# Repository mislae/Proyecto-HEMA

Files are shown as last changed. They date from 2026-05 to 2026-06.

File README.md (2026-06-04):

# Proyecto HEMA: Robot humanoide de 1 m

## Estado del proyecto
Proyecto HEMA esta actualmente en fase de diseno mecanico, bocetaje y validacion CAD 3D. El foco real del repositorio es el conjunto pie-tobillo y la estructura fisica necesaria para probar el primer prototipo.

En esta etapa no hay desarrollo de software activo en el alcance principal. Esos temas quedan como roadmap futuro, pero no deben confundirse con el entregable actual.

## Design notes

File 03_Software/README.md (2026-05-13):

# Software & Control Roadmap - Proyecto HEMA

Este módulo gestiona la inteligencia y el movimiento del robot, utilizando una arquitectura híbrida entre procesamiento de alto nivel (RPi 4B) y control de tiempo real (RPi Pico).

## 🧠 Control Architecture

*   **High-Level Logic (Raspberry Pi 4B):** Encargada de la visión computacional, cinemática inversa y la interfaz de teleoperación con **Meta Quest 3S**.
*   **Low-Level Actuation (Raspberry Pi Pico):** Encargada de la generación de señales PWM para los servos MG995 y la lectura de sensores locales.

---

## 🚀 Development Phases

### Phase 1: Basic Motion & PWM (Current)
*   **Target:** Raspberry Pi Pico.
*   **Tasks:**
    *   Implementación de drivers básicos en **MicroPython** para el control de posición de servos.
    *   Calibración del rango de movimiento del tobillo ($\pm 25^\circ$).
    *   Pruebas de torque estático bajo carga del frame de 1 metro.

### Phase 2: Smooth Motion & Kinematics
*   **Target:** RPi Pico + RPi 4B.
*   **Tasks:**
    *   Implementación de curvas de aceleración (Ease-in/out) para reducir el estrés mecánico en las piezas de **PETG**.
    *   Desarrollo de una API de comunicación serial (UART) entre ambos controladores.
    *   Cálculo de la cinemática del sistema de varillas (mapeo de grados del servo vs. grados reales del tobillo).

### Phase 3: Teleoperation & VR Integration
*   **Target:** RPi 4B + Meta Quest 3S.
*   **Tasks:**
    *   Transmisión de datos de teleoperación mediante **UDP/WebSockets**.
    *   Sincronización del pitch del tobillo con los sensores de movimiento del visor VR.
    *   Monitoreo de telemetría en tiempo real (consumo de corriente y ángulos).

---

## 🛠️ Tech Stack
*   **Languages:** Python 3.x, MicroPython.
*   **Communication:** UART, I2C, WebSockets.
*   **Libraries:** `machine` (Pico), `pyserial`, `numpy` (for kinematics).

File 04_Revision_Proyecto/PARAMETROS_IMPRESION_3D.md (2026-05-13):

# Parametros de impresion 3D - Proyecto HEMA

## Proposito
Este documento define el minimo tecnico que debe registrarse para imprimir piezas estructurales del Proyecto HEMA.

## Regla base
Cada pieza importante debe imprimirse con parametros conocidos y repetibles. No basta con decir "PETG" o "ABS"; hay que poder reproducir la pieza con el mismo comportamiento mecanico.

## Campos que deben documentarse por pieza
- Material
- Altura de capa
- Numero de perímetros
- Relleno
- Porcentaje de relleno
- Tipo de soportes
- Orientacion de impresion
- Temperatura de boquilla
- Temperatura de cama
- Zona critica de carga
- Observaciones de postproceso

## Recomendacion de documentacion minima
Para cada pieza estructural, registrar al menos:
- nombre de la pieza
- version
- material usado
- orientacion de impresion
- razon de esa orientacion
- si requiere soportes o no
- ajuste esperado con piezas comerciales

## Piezas que requieren mas cuidado
- Alojamiento del tubo PVC
- Soporte del tobillo
- Brazos de linkage
- Soportes del servo
- Cualquier pieza que reciba carga concentrada o vibracion repetida

## Buenas practicas
- Orientar las capas para que no trabajen en la direccion mas debil de la pieza.
- Evitar soportes innecesarios en superficies funcionales.
- Preferir geometria simple si reduce riesgo de delaminacion.
- Hacer una prueba corta si se cambia material o relleno.

## Criterio de decision
Si una pieza es estructural y soporta carga, su configuracion de impresion debe quedar escrita antes de fabricar el lote final.

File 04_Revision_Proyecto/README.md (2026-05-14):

# Documentacion tecnica - Proyecto HEMA

Esta carpeta contiene documentacion de trabajo para la fase mecanica del proyecto.

## Uso diario
- `CHECKLIST_OPERATIVA.md`: control rapido antes de exportar, fabricar o cerrar una revision.
- `GUIA_ENSAMBLAJE.md`: secuencia de montaje y criterios de aceptacion del conjunto pie-tobillo.
- `PARAMETROS_IMPRESION_3D.md`: registro minimo para piezas impresas estructurales.

## Uso de coordinacion
- `GUIA_MECANICA_Y_FLUJO.md`: reglas de colaboracion, versionado CAD y publicacion.

## Uso historico
- `REVISION_TECNICA_HEMA.md`: diagnostico inicial que explica por que se ordeno esta carpeta.

## Orden recomendado para trabajar
1. Planificar cambio con `GUIA_MECANICA_Y_FLUJO.md`.
2. Validar salida con `CHECKLIST_OPERATIVA.md`.
3. Si hay pieza impresa, registrar en `PARAMETROS_IMPRESION_3D.md`.
4. Si afecta montaje, revisar `GUIA_ENSAMBLAJE.md`.

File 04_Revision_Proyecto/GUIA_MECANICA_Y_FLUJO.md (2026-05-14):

# Guia mecanica y flujo de trabajo - Proyecto HEMA

## Proposito
Esta guia define como trabajar el proyecto HEMA en su fase actual: diseno CAD, validacion mecanica y prototipado fisico del tobillo humanoide.

El objetivo es que dos personas puedan colaborar sin pisarse cambios, sin sobreescribir piezas y con una trazabilidad tecnica clara.

## Regla base de alcance
* Lo que vive en Fusion 360 es el modelo maestro.
* Lo que se sube al repositorio es la version controlada en STEP, PDF y notas tecnicas.
* El repositorio no debe convertirse en un archivo caotico de exportaciones no verificadas.

## Flujo de trabajo recomendado
### 1. Definir la tarea
Antes de abrir Fusion 360, la pieza o modificacion debe tener claro:
* problema mecanico a resolver
* pieza afectada
* riesgo tecnico
* criterio de exito

### Checklist operativa
Usa la lista de [CHECKLIST_OPERATIVA.md](CHECKLIST_OPERATIVA.md) antes de exportar cualquier nueva revision.
La idea es que la revision no dependa de memoria ni de revisiones informales.

### 2. Trabajar en una rama dedicada
Cada cambio mecanico debe desarrollarse en su propia rama.
* Una rama por pieza o por mejora concreta.
* No mezclar cambios de distintas zonas del robot en una sola entrega.

### 3. Exportar con version controlada
Nunca sobrescribir un STEP antiguo sin dejar rastro.
* Usar versionado explicito en el nombre del archivo.
* Mantener una secuencia clara: v1, v2, v3.
* Si una version queda descartada, no eliminarla sin documentarlo.

### 4. Registrar el cambio
Cada exportacion debe dejar nota en `01_Mechanical/DESIGN_LOG.md` con:
* que se modifico
* por que se modifico
* que problema tecnico corrige
* que queda pendiente de validar

### 5. Revisar antes de cerrar
Antes de aprobar una revision:
* comprobar interferencias
* revisar tolerancias
* verificar accesibilidad de tornillos y herramientas
* confirmar que el recorrido mecanico no bloquea

## Nomenclatura sugerida
Usar una convención simple y repetible:
* `HEMA_Pieza_v1.step`
* `HEMA_Pieza_v2.step`
* `HEMA_Conjunto_Tobillo_v3.step`

Para planos:
* `HEMA_Pieza_v1.pdf`
* `HEMA_Conjunto_Tobillo_v3.pdf`

## Reglas para evitar conflictos entre dos personas
* No editar el mismo subconjunto de Fusion 360 al mismo tiempo sin coordinacion previa.
* Si una persona modifica geometria estructural, la otra debe revisar tolerancias, ensamble o fabricacion, no tocar la misma pieza a la vez.
* Si hay dudas sobre la version correcta, se consulta el `DESIGN_LOG` antes de exportar otra revision.
* Nadie reemplaza archivos en silencio.

## Checklist tecnico antes de publicar una pieza
Esta validacion se ejecuta en `CHECKLIST_OPERATIVA.md`.
No dupliques esa lista aqui para evitar versiones inconsistentes.

## Parametros de impresion 3D que deben documentarse
Se documentan en `PARAMETROS_IMPRESION_3D.md`.
Este archivo solo define el flujo y la responsabilidad de hacerlo.

## Que debe existir en un hardware open-source serio
Este proyecto deberia terminar con al menos:
* guia de ensamblaje
* BOM mecanico completo
* parametros de impresion 3D
* tolerancias criticas
* vistas explotadas o subconjuntos
* protocolo de validacion del prototipo

## Orden de ataque recomendado
### Bloque 1: cierre mecanico
* resolver ajuste tubo PVC / alojamiento impreso
* definir abrazadera o sistema de retencion
* cerrar la tornilleria del tobillo

### Bloque 2: fabricacion
* fijar parametros de impresion
* verificar orientacion de carga
* preparar piezas para primer prototipo

### Bloque 3: validacion
* ensayo de carga estatica
* revision de juego mecanico
* control del desgaste inicial

## Criterio de calidad
La revision va bien si una persona externa puede responder sin adivinar:
* que pieza necesita
* como la imprime
* con que la ensambla
* que tolerancias son criticas
* como sabe si funciona o no

## Nota final
Mantener el proyecto simple no significa hacerlo superficial. Significa documentar solo lo necesario, pero hacerlo con rigor suficiente para que el conjunto sea reproducible y defendible tecnicamente.

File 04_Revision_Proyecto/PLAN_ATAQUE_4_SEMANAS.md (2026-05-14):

# Plan de ataque de 4 semanas - Proyecto HEMA

## Objetivo
Convertir el conjunto pie-tobillo en un prototipo mecanico reproducible, con tolerancias, ensamble y validacion minima cerrados.

## Tablero Kanban (seguimiento rapido)

| ID | Tarea | Responsable | Estado |
| :-- | :-- | :-- | :-- |
| W1-01 | Resolver holgura PVC-alojamiento | Martin / Companero | Todo |
| W1-02 | Definir retencion final (abrazadera/interferencia/hibrido) | Martin / Companero | Todo |
| W1-03 | Verificar recorrido completo sin interferencias | Martin / Companero | Todo |
| W2-01 | Cerrar tornilleria real en BOM | Martin / Companero | Todo |
| W2-02 | Definir parametros de impresion por pieza | Martin / Companero | Todo |
| W2-03 | Imprimir primera tanda de piezas | Martin / Companero | Todo |
| W3-01 | Ensamblar subconjunto pie-tobillo | Martin / Companero | Todo |
| W3-02 | Registrar incidencias de montaje | Martin / Companero | Todo |
| W3-03 | Corregir geometria por ajustes forzados | Martin / Companero | Todo |
| W4-01 | Ejecutar ensayo estatico de carga | Martin / Companero | Todo |
| W4-02 | Validar repetibilidad de movimiento | Martin / Companero | Todo |
| W4-03 | Revisar holguras y desgaste inicial | Martin / Companero | Todo |

Estados sugeridos: `Todo`, `Doing`, `Done`, `Blocked`.

## Reglas de uso del tablero
- Actualizar estado al cierre de cada jornada, no solo al final de la semana.
- Si una tarea queda en `Blocked`, anotar causa y siguiente accion en `01_Mechanical/DESIGN_LOG.md`.
- Si una tarea pasa a `Done`, verificar que tenga evidencia (STEP, BOM, nota tecnica o registro de prueba).
- No abrir tareas nuevas sin cerrar o desbloquear las criticas de la semana actual.

## Semana 1: Cierre de geometria critica
- Resolver holgura PVC-alojamiento.
- Definir estrategia de retencion final (abrazadera, interferencia o hibrido).
- Verificar recorrido completo del tobillo sin interferencias.
- Salida esperada: nuevo STEP de conjunto y nota tecnica en DESIGN_LOG.

## Semana 2: Tornilleria y fabricacion
- Cerrar lista de tornilleria real en BOM.
- Definir parametros de impresion para piezas estructurales.
- Imprimir primera tanda de piezas del tobillo.
- Salida esperada: BOM actualizado y registro de impresion por pieza.

## Semana 3: Ensamble y correcciones
- Ensamblar subconjunto completo pie-tobillo.
- Levantar incidencias de montaje y accesibilidad de herramientas.
- Corregir geometria si aparecen ajustes forzados.
- Salida esperada: guia de ensamblaje con observaciones reales del prototipo.

## Semana 4: Validacion mecanica minima
- Ensayo estatico de carga.
- Repetibilidad de movimiento en el rango objetivo.
- Revision de holguras y desgaste inicial.
- Salida esperada: estado de validacion documentado y decision de siguiente iteracion.

## Criterio de exito
Al final de la semana 4, una persona externa debe poder:
- entender que piezas fabricar,
- ensamblarlas sin improvisar,
- y evaluar si el conjunto cumple o no con criterios basicos.

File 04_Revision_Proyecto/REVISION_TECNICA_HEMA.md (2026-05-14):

# Revision tecnica del Proyecto HEMA

## Estado de este documento
Este archivo queda como informe historico del diagnostico inicial.

No es la fuente operativa para el trabajo diario. Para ejecutar tareas usa:
- `CHECKLIST_OPERATIVA.md`
- `GUIA_MECANICA_Y_FLUJO.md`
- `GUIA_ENSAMBLAJE.md`
- `PARAMETROS_IMPRESION_3D.md`

## Resumen ejecutivo del diagnostico inicial
1. El foco correcto del proyecto es mecanica, CAD y prototipado fisico del tobillo.
2. El repositorio necesitaba separar alcance actual de roadmap futuro para no confundir evaluadores.
3. Faltaban piezas clave de reproducibilidad: ensamblaje, parametros de impresion y flujo de colaboracion.

## Riesgos tecnicos detectados
- Holgura de 1.3 mm entre tubo PVC y alojamiento impreso.
- Falta de cierre completo de tornilleria y retencion.
- Necesidad de validar par disponible del sistema servo-varillaje.
- Riesgo de interferencias en el recorrido completo del tobillo.

## Accion aplicada
Este diagnostico ya fue incorporado a la documentacion operativa de la carpeta 04 y al README principal.

## Criterio de cierre
Se considera cerrado cuando una persona externa puede fabricar, ensamblar y revisar el conjunto sin adivinar decisiones criticas.

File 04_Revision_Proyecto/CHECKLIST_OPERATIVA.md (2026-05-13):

# Checklist operativa - Proyecto HEMA

## Antes de abrir Fusion 360
- [ ] La pieza o cambio esta definido con una necesidad mecanica concreta.
- [ ] La zona del robot afectada esta identificada.
- [ ] El riesgo tecnico principal esta escrito en una frase.
- [ ] El criterio de exito esta claro.

## Antes de exportar un STEP
- [ ] La geometria nueva fue revisada con la version anterior.
- [ ] No hay interferencias evidentes con piezas vecinas.
- [ ] El recorrido mecanico completo es posible sin bloqueo.
- [ ] La solucion de retention o sujecion esta resuelta.
- [ ] La tolerancia de ensamble esta justificada.

## Antes de publicar una nueva revision
- [ ] El archivo tiene version explicita en el nombre.
- [ ] El cambio quedo registrado en `01_Mechanical/DESIGN_LOG.md`.
- [ ] Se guardo una nota de por que se cambio la pieza.
- [ ] Se indico que queda pendiente de validar.
- [ ] El STEP anterior no fue sobrescrito sin trazabilidad.

## Antes de comprar o fabricar
- [ ] La tornilleria asociada esta definida.
- [ ] Los materiales necesarios estan en el BOM.
- [ ] Los parametros de impresion 3D estan documentados o al menos definidos.
- [ ] La pieza puede montarse y desmontarse con herramientas normales.
- [ ] La fabricacion no depende de ajustes improvisados.

## Antes de cerrar la iteracion
- [ ] El cambio mejora una variable mecanica real.
- [ ] La solucion sigue siendo simple de fabricar para un equipo pequeno.
- [ ] El prototipo puede evaluarse sin redisenar todo el conjunto.
- [ ] El siguiente paso tecnico esta escrito.

## Regla final
Si una casilla critica queda sin marcar, la pieza no se publica como version final.

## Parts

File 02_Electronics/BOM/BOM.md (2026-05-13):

# Bill of Materials (BOM) - Proyecto HEMA

## Alcance actual
Este BOM esta centrado en la fase mecanica y de prototipado fisico del tobillo humanoide. Los elementos de software, teleoperacion y VR quedan fuera del alcance activo de esta revision.

## Componentes confirmados
| Componente | Cantidad | Funcion principal |  Estado |
| :--- | :---: | :--- | :---: |
| **Servo MG995** | 1 | Actuador principal del tobillo. | Adquirido |
| **Rodamiento 608ZZ** | 2 | Pivotes de baja friccion para la articulacion. | Adquirido |
| **Tubo PVC 20 mm** | 1 m | Estructura principal de la tibia durante el prototipado. | Adquirido |
| **Filamento PETG o ABS** | 1 kg | Impresion 3D de piezas estructurales y soportes. | Pendiente |

## Componentes mecanicos por definir
| Componente | Cantidad | Funcion principal |  Estado |
| :--- | :---: | :--- | :---: |
| **Tornillos M3 cabeza cilíndrica** | 8 | Union general de soportes impresos y piezas de carcasa. | Pendiente |
| **Tornillos M3 avellanados** | 4 | Cierre de tapas o piezas donde la cabeza no debe sobresalir. | Pendiente |
| **Tornillos M4 para clamp** | 2 | Cierre de abrazadera del tubo PVC. | Pendiente |
| **Tuercas autoblocantes M3** | 8 | Retencion de uniones con vibracion. | Pendiente |
| **Tuercas M4 autoblocantes** | 2 | Retencion del sistema de abrazadera. | Pendiente |
| **Arandelas planas M3** | 16 | Distribucion de carga y separacion. | Pendiente |
| **Arandelas planas M4** | 4 | Apoyo en la abrazadera del tubo PVC. | Pendiente |
| **Insertos termicos M3** | 6 | Rosca metalica en piezas impresas. | Pendiente |
| **Fijador de roscas medio** | 1 | Prevencion de aflojamiento por vibracion. | Pendiente |
| **Pasador o eje secundario 8 mm**  | 1 | Retencion o guia de componentes moviles segun el conjunto final. | Pendiente |

## Componentes fuera del alcance activo
| Componente | Cantidad | Funcion principal | Estado |
| :--- | :---: | :--- | :----: |
| **Raspberry Pi 4B** | 1 | Control de alto nivel y logica de software. | Futuro |
| **Raspberry Pi Pico** | 1 | Control de bajo nivel y PWM. | Futuro |
| **Meta Quest 3S** | 1 | Teleoperacion y VR. | Futuro |

## Observaciones tecnicas
* El BOM mecanico debe cerrarse antes de fabricar una nueva iteracion del tobillo.
* La tornilleria y los elementos de retencion no pueden quedar como decisiones informales.
* Cada pieza comercial debe quedar ligada a una referencia concreta en CAD o en la guia de ensamblaje.
* Las cantidades anteriores son preliminares y deben ajustarse al ensamblaje final antes de comprar lote completo.

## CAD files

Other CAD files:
01_Mechanical/CAD/Pie+Tobillo Prototipo 1.step
01_Mechanical/CAD/HEMA_PIE-001_2.0.0.step
01_Mechanical/CAD/HEMA_PIE-001_1.0.0.step
01_Mechanical/CAD/HEMA_ANK-001_1.0.0.step
01_Mechanical/CAD/5972K91_Steel Ball Bearing.f3d
01_Mechanical/CAD/90035A234_High-Strength A286 Stainless Steel Socket Head Screw.f3d
01_Mechanical/CAD/Ankle Joint.f3d
01_Mechanical/CAD/Componente13.f3d
01_Mechanical/CAD/Componente3.f3d
01_Mechanical/CAD/Pieza para rodilla.f3d
01_Mechanical/CAD/Servo MG995R.f3d
01_Mechanical/CAD/Spur Gear 45 teeth.f3d

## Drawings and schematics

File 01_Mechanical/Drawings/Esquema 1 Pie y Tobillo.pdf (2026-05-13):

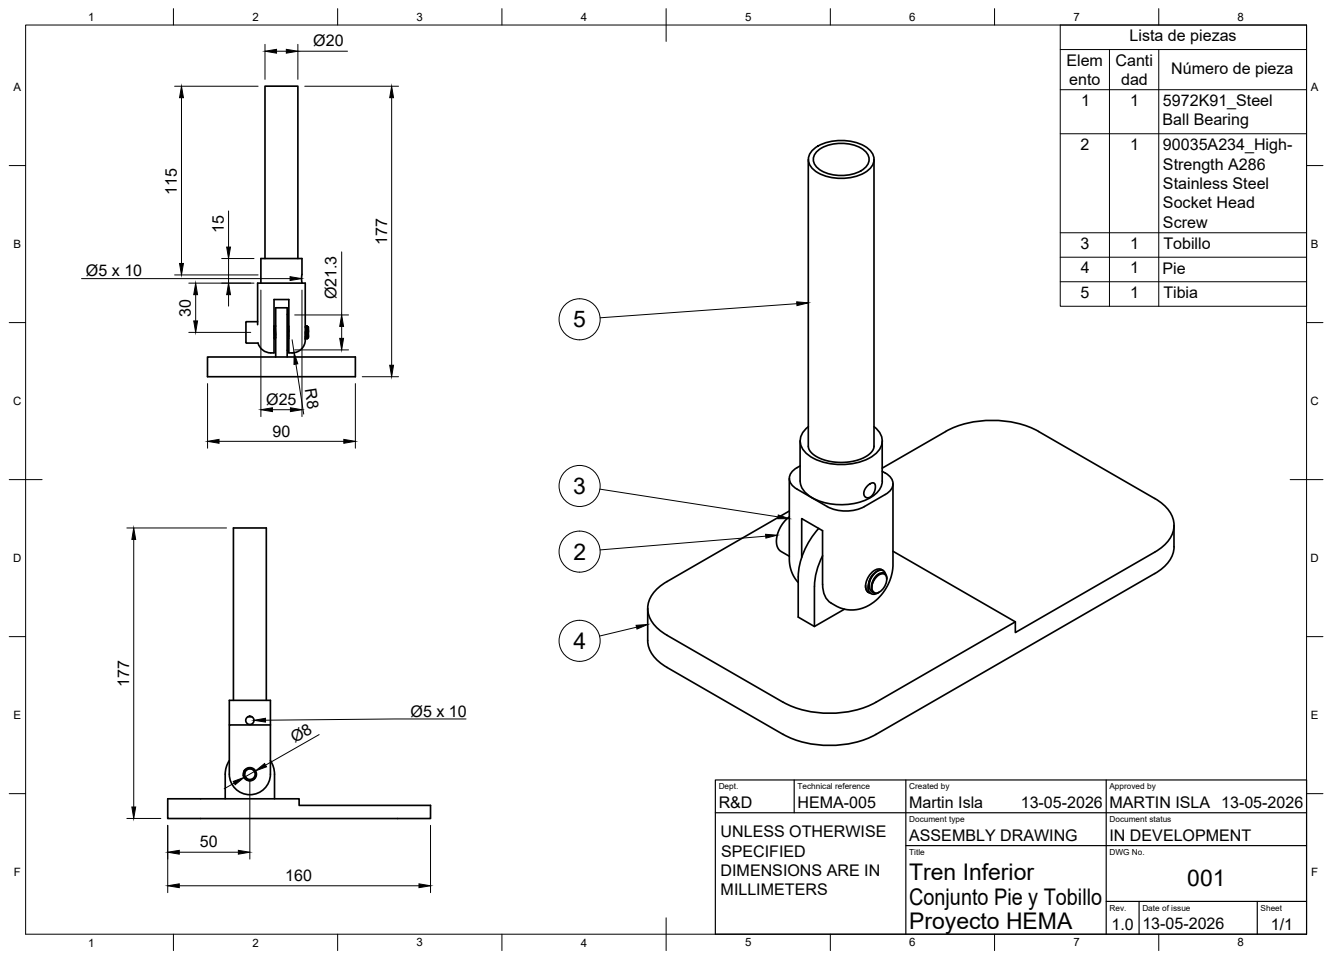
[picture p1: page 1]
Title; DWG No.; Rev.; Date of issue; Sheet; Proyecto HEMA; Tren Inferior; UNLESS OTHERWISE

Lista de piezas

Elem ento | Canti dad | Número de pieza

1 | 1 | 5972K91_Steel Ball Bearing

2 | 1 | 90035A234_High-Strength A286 Stainless Steel Socket Head Screw

3 | 1 | Tobillo
4 | 1 | Pie
5 | 1 | Tibia

Dept. R&D | Technical reference HEMA-005 | Created by Martin Isla 13-05-2026 | Approved by MARTIN ISLA 13-05-2026

Document type ASSEMBLY DRAWING | Document status IN DEVELOPMENT

SPECIFIED
DIMENSIONS ARE IN
MILLIMETERS

Conjunto Pie y Tobillo

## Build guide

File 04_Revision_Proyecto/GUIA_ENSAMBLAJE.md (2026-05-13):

# Guia de ensamblaje - Proyecto HEMA

## Alcance
Esta guia cubre el ensamble mecanico del conjunto pie-tobillo del Proyecto HEMA en su fase de prototipo.

## Principio general
El ensamblaje debe poder hacerse sin forzar piezas ni improvisar ajustes de ultima hora. Si una union requiere esfuerzo excesivo, primero se revisa tolerancia y geometria, no se fuerza la pieza.

## Orden recomendado de ensamble
### 1. Verificacion previa
- Confirmar que se tiene la version correcta del STEP y del plano PDF.
- Revisar que la tornilleria necesaria este disponible.
- Verificar que las piezas impresas no tengan deformacion visible.

### 2. Subconjunto del tobillo
- Montar los rodamientos 608ZZ en sus alojamientos.
- Confirmar que el eje o elemento rotativo gire sin rozamiento anormal.
- Revisar que no exista juego axial excesivo.

### 3. Union del tubo PVC
- Insertar el tubo PVC de 20 mm en el alojamiento impreso.
- Verificar si la holgura exige abrazadera, fijacion por tornillo o retencion combinada.
- No cerrar el conjunto hasta comprobar alineacion y concentricidad.

### 4. Montaje del servo y linkage
- Instalar el MG995 en su soporte.
- Ensamblar la varilla o sistema pushrod.
- Revisar que el movimiento completo no genere interferencias.

### 5. Cierre final
- Instalar tornilleria, arandelas, tuercas autoblocantes e insertos termicos segun el BOM.
- Aplicar fijador de roscas solo donde este definido.
- Verificar que todo el conjunto pueda desmontarse para mantenimiento.

## Puntos criticos de revision
- El tobillo debe moverse libremente en todo el rango de trabajo.
- No debe haber contacto no deseado entre varillaje y piezas impresas.
- El tubo PVC no debe quedar retenido de forma ambigua.
- La tornilleria debe quedar accesible para herramientas normales.

## Criterios de aprobacion
El ensamble se considera aceptable si:
- el movimiento es suave,
- la retencion del tubo es estable,
- la pieza no presenta holguras evidentes,
- y el montaje puede repetirse con el mismo resultado.

## Observacion final
Si la geometria obliga a forzar el montaje, la solucion correcta es redisenar la pieza o ajustar tolerancias, no compensar con presion indebida.

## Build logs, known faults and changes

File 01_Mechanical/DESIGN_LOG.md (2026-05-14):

# Engineering Design Log: HEMA Project

## Entry 01: Ankle Joint v4 Review
**Date:** May 13, 2026
**Author:** Martin Isla Escudero
**Subsystem:** Mechanical / Ankle
**Status:** In review

### 1. Objective
Define a mechanically compact ankle joint for a 1 m humanoid frame while keeping the distal mass as low as possible.

### 2. Engineering context
The current concept uses a pushrod linkage to move the MG995 away from the foot and a pair of 608ZZ bearings to support the rotary joint. The tibia prototype is based on 20 mm PVC tubing combined with 3D printed interfaces.

### 3. Design decisions
* **Pushrod linkage:** selected to reduce unsprung mass at the foot and keep the servo higher in the leg.
    * Rationale: lower inertia at the distal end improves dynamic response and reduces the torque penalty during leg motion.
* **608ZZ bearings:** selected as the primary pivot support.
    * Rationale: standard, low-cost, easy to source, and adequate for the radial loads expected in this prototype stage.
* **20 mm PVC structural tube:** selected as the tibia core during prototyping.
    * Rationale: fast to source, simple to machine, and sufficient for early fit-checks before moving to a more optimized structural solution.

### 4. Constraints and target values
* **Degrees of freedom:** 1 axis, pitch.
* **Range of motion:** +/-25 degrees.
* **Target safety factor:** 1.5x the estimated static load of the upper assembly.
* **Assembly goal:** no forced fit that requires uncontrolled sanding or ad hoc reshaping during assembly.

### 5. Open technical issues
* **PVC-to-socket fit:** current CAD indicates a 1.3 mm gap between the PVC tube and the 3D printed tibia socket.
* **Retention strategy:** the joint still needs a final decision between clamp-style retention, interference fit, or a hybrid solution.
* **Torque path:** the servo horn and rocker geometry still need to be finalized to confirm the 3:1 mechanical advantage.

### 6. Validation plan
* Verify the actual clearance between printed parts and the PVC tube after export.
* Check whether the clamp can absorb print variation without over-stressing the socket.
* Confirm that the linkage does not collide through the full +/-25 degree travel.
* Estimate the available torque margin at the worst-case ankle position.

### 7. Next iteration
Prepare the servo horn and rocker arm geometry, then close the retention concept for the PVC tube before moving to a new prototype export.

---

## Version entry template (copy/paste)
Use this template for each new exported revision.

### Entry XX: [Part name] vX.Y.Z
**Date:** YYYY-MM-DD
**Author:** [Name]
**Subsystem:** Mechanical / [Area]
**Part ID:** [ANK-001]
**Status:** Draft | In review | Released

### 1. Previous version
* [vX.Y.Z]

### 2. Why this change
* [Technical reason in one sentence]

### 3. Change scope
* [What changed in geometry/tolerance/interface]

### 4. Version type
* **Type:** Major | Minor | Patch
* **Justification:** [Why this type applies]

### 5. Expected impact
* [Assembly impact]
* [Manufacturing impact]
* [Validation impact]

### 6. Pending validation
* [ ] Interference check completed
* [ ] Full travel check completed
* [ ] Fasteners/retention defined
* [ ] BOM impact updated (if needed)

### 7. Exported files
* [HEMA_ANK-001_socket-tibia_vX.Y.Z.step]
* [HEMA_ANK-001_socket-tibia_vX.Y.Z.pdf]

### 8. Next action
* [Single clear next technical step]

---

## Entry 02: Pie v1.0.0
**Date:** 2026-05-13
**Author:** Martin Isla Escudero
**Subsystem:** Mechanical / Pie
**Part ID:** PIE-001
**Status:** Released (publicado)

### 1. Previous version
* [none]

### 2. Why this change
* Publicacion inicial del modelo 3D del pie para revisiones de montaje y ajuste.

### 3. Change scope
* Exportacion inicial de geometria completa del pie.

### 4. Version type
* **Type:** Major
* **Justification:** Primera version publica del componente.

### 5. Expected impact
* Disponible para revisiones de interferencia y ensamblaje.

### 6. Pending validation
* [ ] Interference check completed
* [ ] Full travel check completed
* [ ] Fasteners/retention defined
* [ ] BOM impact updated (if needed)

### 7. Exported files
* 01_Mechanical/CAD/HEMA_PIE-001_1.0.0.step

### 8. Next action
* Ejecutar checklist operativo y actualizar estado.

---

## Entry 03: Ankle v1.0.0
**Date:** 2026-05-13
**Author:** Martin Isla Escudero
**Subsystem:** Mechanical / Ankle
**Part ID:** ANK-001
**Status:** Released (publicado)

### 1. Previous version
* [none]

### 2. Why this change
* Publicacion inicial del modelo 3D del conjunto de tobillo para validacion de geometria.

### 3. Change scope
* Exportacion inicial del housing y geometria de montaje del tobillo.

### 4. Version type
* **Type:** Major
* **Justification:** Primera version publica del componente.

### 5. Expected impact
* Disponible para revisar ajuste con la tibia y el pie.

### 6. Pending validation
* [ ] Interference check completed
* [ ] Full travel check completed
* [ ] Fasteners/retention defined
* [ ] BOM impact updated (if needed)

### 7. Exported files
* 01_Mechanical/CAD/HEMA_ANK-001_1.0.0.step

### 8. Next action
* Ejecutar checklist operativo y actualizar estado.

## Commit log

2026-05-13 feat: initial mechanical design of the ankle joint
    Initial CAD files (.step) and technical drawings for the HEMA Project. Includes ankle range of motion specs (±25°).
    [Pie+Tobillo Prototipo 1.step]
2026-05-13 Add mechanical design log and software roadmap
    Add an engineering design log for the ankle joint (01_Mechanical/DESIGN_LOG.md) capturing design decisions, specs, constraints, known issues and next steps (author: Martin Isla Escudero, 2026-05-13). Add a Spanish software/control roadmap (03_Software/README.md) outlining RPi 4B/RPi Pico architecture, development phases, and tech stack. Remove placeholder .gitkeep files from 02_Electronics and 03_Software. Update top-level README to include the software module and add a References & Inspiration section.
2026-05-13 docs: add BOM and contribution guidelines for team workflow
2026-05-13 Add CAD issue template (nueva_pieza_cad.md)
    Add a new GitHub issue template in Spanish for requesting new CAD parts or design modifications (Fusion 360). Includes sections for need description, technical specifications (material, tolerances, weight), references, and applies labels 'mechanical' and 'enhancement'.
2026-05-13 Add mechanical review docs and update BOM & guides
    Add a new documentation folder (04_Revision_Proyecto) containing: CHECKLIST_OPERATIVA.md, GUIA_ENSAMBLAJE.md, GUIA_MECANICA_Y_FLUJO.md, PARAMETROS_IMPRESION_3D.md, REVISION_TECNICA_HEMA.md and a README summarizing the review materials. Update/design docs to reflect a mechanical-first scope: expand 01_Mechanical/DESIGN_LOG.md with a detailed ankle v4 review, refocus 02_Electronics/BOM/BOM.md to emphasize mechanical/prototyping items and add hardware-to-define lists, and revise CONTRIBUTING.md and top-level README.md to clarify workflow, versioning, branch rules and the current project scope (mechanical prototyping, tolerances, BOM and validat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
2026-05-14 Remove 04_Revision_Proyecto documentation
    Delete obsolete/historical operational documents from 04_Revision_Proyecto. Removed files: GUIA_ENSAMBLAJE.md, GUIA_MECANICA_Y_FLUJO.md, PLAN_ATAQUE_4_SEMANAS.md, README.md, REVISION_TECNICA_HEMA.md.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
2026-05-14 docs: define CAD versioning policy and add LFS rules
2026-05-14 Split combined STEP into ankle and foot files
    Replace the monolithic 01_Mechanical/CAD/Pie+Tobillo Prototipo 1.step with two modular STEP files tracked via Git LFS: 01_Mechanical/CAD/HEMA_ANK-001_1.0.0.step (LFS pointer, size 49634) and 01_Mechanical/CAD/HEMA_PIE-001_1.0.0.step (LFS pointer, size 24288). Also remove 01_Mechanical/DESIGN_LOG.md. This reorganizes CAD assets into separate ankle and foot models and moves large binary data into Git LFS for easier repo management.
    [HEMA_ANK-001_1.0.0.step, HEMA_PIE-001_1.0.0.step, Pie+Tobillo Prototipo 1.step]
2026-05-16 Add PIE v2.0 CAD/STL and drawing; remove DESIGN_LOG
    Add exported foot model HEMA_PIE-001_2.0.0 (STEP and STL) and associated drawing (Esquema 3 Pie-Tobillo.pdf) tracked via Git LFS. Remove outdated 01_Mechanical/DESIGN_LOG.md. These changes publish th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
    [HEMA_PIE-001_2.0.0.step]
2026-06-09 Avances Diseño
    Implementacion Rodilla, inicio esquema electrico
    [5972K91_Steel Ball Bearing.f3d, 90035A234_High-Strength A286 Stainless Steel Socket Head Screw.f3d, Ankle Joint.f3d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]
